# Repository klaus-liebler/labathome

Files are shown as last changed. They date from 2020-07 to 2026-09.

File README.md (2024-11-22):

# lab@home

<a target="_blank" href="https://icons8.com/icon/cUjTrEUoGJ2Z/xing">Xing</a> icon by <a target="_blank" href="https://icons8.com">Icons8</a>
<a target="_blank" href="https://icons8.com/icon/3tC9EQumUAuq/github">GitHub</a> icon by <a target="_blank" href="https://icons8.com">Icons8</a>
<a target="_blank" href="https://icons8.com/icon/IuI5Yd3J3qcC/linkedin">LinkedIn</a> icon by <a target="_blank" href="https://icons8.com">Icons8</a>

## Was steckt dahinter?
Das Projekt "lab@home" entstand zu Beginn der Corona-Pandemie. Als Lehrer in einer Hochschule der angewandten Wissenschaften war es dem Initiator ein Anliegen, seinen Studierenden auch 
während des Lockdowns Zugang zu Laborexperimenten in den Bereichen Steuerungstechnik, Regelungstechnik und Informationstechnik zu geben. Leider konnten die Studierenden nicht
mehr in die Hochschullabors, also musste das Labor zu den Studierenden. Nur leider wäre ein Container voll Material pro Student etwas zu aufwändig. Etwas kleineres und vor allem
kostengünstigeres musste her. Und damit waren die grundsätzlichen Anforderungen umrissen und der Initiator machte mich ans Design...

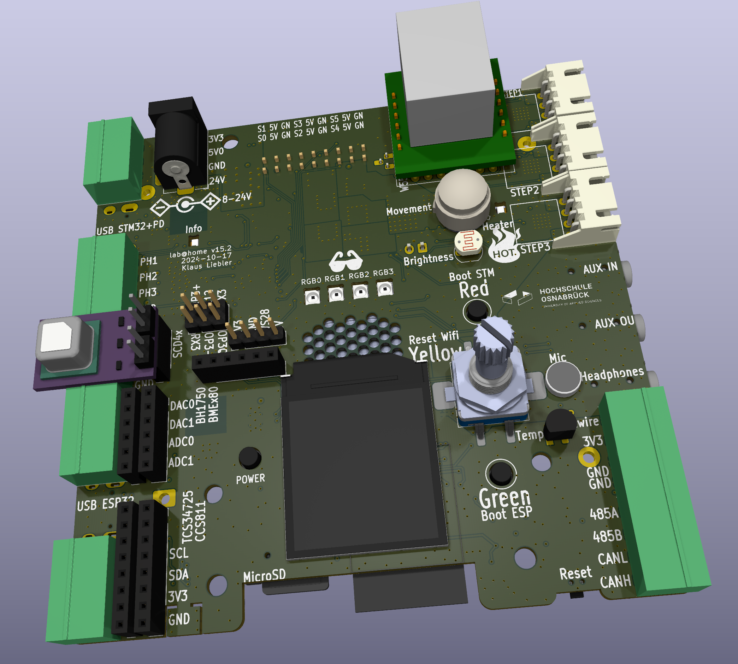
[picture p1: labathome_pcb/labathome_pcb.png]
Rendering


## Was gehört zu lab@home und was kann man damit machen?
Lab@home besteht aus
- einem Hardware-Design
- einer Softwarekomponente
- dieser Dokumentation
- der Beschreibung von Laborexperimenten (nicht veröffentlicht, auf Anfrage stelle ich das gerne zur Verfügung)

Der Entwickler bezeichne lab@home als eine Lehr- und Lernplattform für den Einsatz in Bildungseinrichtungen in den Disziplinen Steuerungstechnik, Regelungstechnik und Informationstechnik.
Ein besonderer Fokus liegt dabei auf der Gebäudeautomation

## Was sind die einzigartigen Merkmale von lab@home?
Lab@home
- ist quelloffen und soll unter der MIT-Lizenz jedem Nutzen stiften!
- kann komplett über den Browser bedient werden   
- ist preiswert und unproblematisch nachbaubar
- kann vielfältig eingesetzt werden

## Genug des Blabla - bitte technisch konkret!
Die Hardware von lab@home ist auf einer 10x10cm großen Platine aufgebaut und enthält die folgenden Komponenten:
- Dual-Prozessor-Konzept
    - Applikation: ESP32-S3 (8M Flash, 2,5MB RAM, Wifi, Bluetooth)
    - I/O & Realtime: STM32G431 (128k Flash, 32k RAM)
- Speichererweiteung über microSD-Slot
- Kommunikation
  - Interne Busse: I2c & 1Wire
  - Extern: Wifi, Bluetooth, RS485 (z.B. für Modbus), CAN (z.B. für CANopen oder OBD2)
  - Optional durch Steckmodule: Ethernet (W5500), GSM (SIM7080G), LoRaWan (RFM95), 2,4GHz (NRF24L01)
- Benutzerinteraktion
  - Taster, Inkrementalencoder
  - IPS-Display 240x240 Pixel, 1,3Zoll (ST7789)
  - Vier RGB-LED (WS2812)
  - Lautsprecher, Mikrofon, Klinkenbuchsen für Aux-In, Line-Out, Kopfhörer (NAU88C22)
- Sensorik
  - Lufttemperatur, Temperatur des Heizwiderstandes (2x DS18B20)
  - Luftfeuchtigkeit (SHT20)
  - Umgebungshelligkeit (LDR)
  - Ausrichtungs und Beschleunigungssensor (LSM6DS3)
  - PIR-Bewegungsmelder
  - Drei universelle ADC-Eingänge, davon einer mit Spannungsteiler
  - Spannungs- und Strommessung
  - Eingänge für Hall-Encoder
  - Optional durch Steckmodule: CO2, Luftqualität, Distanzsensor, Farbsensor
- Aktorik
  - Heizwiderstand, Lüfter, weiße Power-LEDs (alle PWM-Ansteuerung)
  - Zwei universelle DAC-Ausgänge, davon einer mit 0-10V
  - Dreiphasiger Motortreiber (Brushless) (DRV8313)
  - Drei Schrittmotor-Treiber (TMC2209)
  - Anschlüsse für vier (optional sechs) Servos
- Stromversorgung
  - USB
  - USB PD oder PPS (max 20V, 5A, umgesetzt über das UCPD-Peripherial im STM32G431)
  - Hohlstecker 5,5mm
  - MC-Klemmen
  - 18650-Akku
  - Involviert in die Stromversorgung sind 
    - IP5306: Akkuladung, Boot-Converter auf 5V
    - TPS54202: Synchroner Abwärtswandler 8...24V -> 5V
    - TPS2116: Umschaltung zwischen Spannungsquellen
    - AMS1117: LDO 5V->3,3V

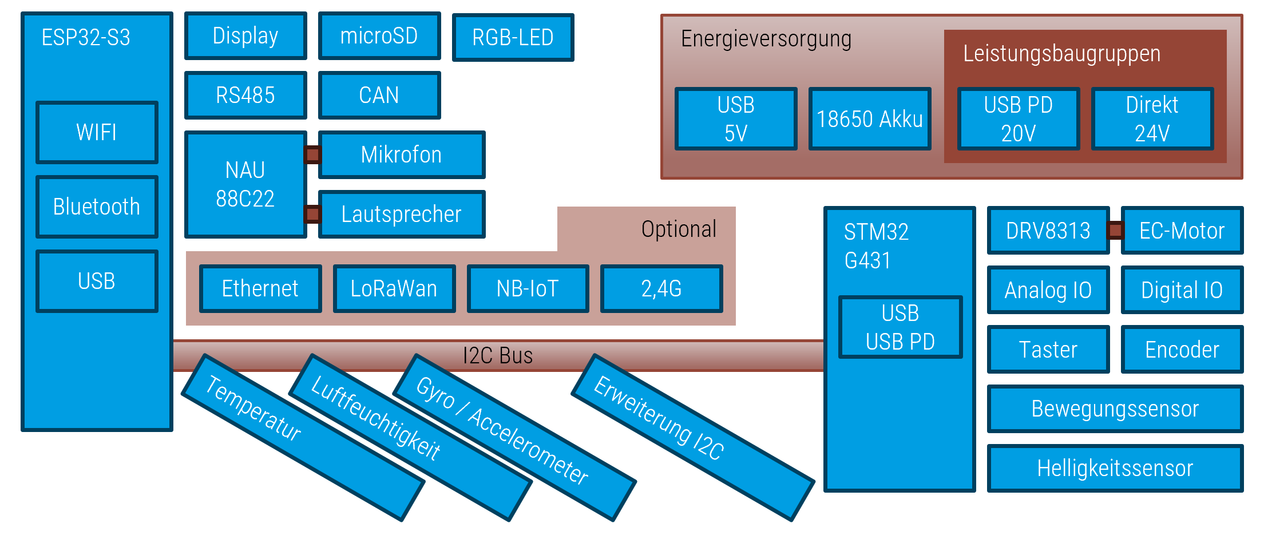
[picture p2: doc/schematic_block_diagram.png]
Blockdiagramm


Die Software von lab@home besteht aus der eigentlichen Firmware und einer Webapplikation. Viele Experimente können über die Webapplikation gesteuert werden.
Nach dem ersten Start öffnet lab@home einen WIFI-Accesspoint, über den die Webapplikation erreichbar ist und labathome auch in ein bestehendes WIFI-Netzwerk eingebunden werden kann. Dank der Webapplikation benötigt der Anwender keine lokale Software und die Nutzung ist unabhängig vom Betriebssystem möglich (viele meiner Studierenden verwenden Apple-Rechner oder haben nur Chromebooks oder Android-Tablets). Die Webapplikation hat diese Features:
- Programmierung von lab@home mit Funktionsblöcken in Anlehnung an IEC61131 und VDI3814
  - darauf ist der Entwickler besonders stolz!!
  - Speichern und Laden von Programmen möglich
  - Es ist möglich, eine Startapplikation festzulegen, die lab@home automatisch beim Einschalten lädt und ausführt
  - Integrierter Debugger
  - Integrierter Simulator
  - Technisches Detail: Das Funktionsblock-Diagramm wird von einem Java-Script-Compiler im Browser zu einem Binärcode compiliert und "online" zum Mikrocontroller gesendet. Dieser bringt dann das Programm unmittelbar zur Ausführung
- Oberfläche für das Experiment "Identikation einer Regelstrecke mit dem Sprungantwort-Versuch"
- Oberfläche für das Experiment "Parametriertung eines PID-Reglers mit der Einstellregeln nach Chien, Hrones und Reswick"
- Konfigurationsoberfläche für Wifi
- Konfigurationsoberfläche für diverse Systemeinstellungen (in Arbeit)
- Online-Aktualisierung der kompletten Systemsoftware (in Arbeit)

# Getting Started - Hardware
Die aktuellen Schaltpläne und Layouts im KiCad-Format befinden sich im Verzeichnis labathome_pcb

# Getting Started - Software

Die Software muss individuell für jedes Board compiliert werden, weil während des von Gulp gesteuerten Gesamt-Build-Prozesses diverse individuelle Dateien erzeugt und eincompiliert werden. Dazu gehören:
- LabAtHome meKicldet sich per Sprachausgabe betriebsbereit. Die Ausgabe enthält auch den Hostnamen der Platine, der sich wiederum aus der MAC-Adresse ableitet. Alle Sprachausgaben werden zum Build-Zeitpunkt über Google TTS erzeugt und in Form von MP3-Dateien im Flash abgelegt. Ach ja, LabAtHome kann natürlich MP3 wiedergeben!
- LabAtHome kommuniziert natürlich verschlüsselt! Dazu wird ein privater Schlüssel und ein Zertifikat für eben den Hostnamen erzeugt

Selbst kompilieren? Geht!
- Installiere das ESP-IDF!
- Installiere Node.js
- Ich gehe davon aus, dass alle Checkouts in c:/repos erfolgen. Viele Pfade sind in den Konfigurationsdateien absolut und auf diesen Pfad angepasst
- Checke dieses Repo https://github.com/klaus-liebler/labathome aus
- Checke das repo https://github.com/klaus-liebler/espidf-components aus
- Rufe "npm update" in C:\repos\labathome\espidf-component-labathome\web auf
- Rufe "npm update" in "C:\repos\labathome\espidf-component-labathome\builder" auf
- Rume "npm run gulp" in "C:\repos\labathome\espidf-component-labathome\builder" auf. Dieses erstellt individuelle Board-Files und die gesamte Web-Anwendung
- TBC

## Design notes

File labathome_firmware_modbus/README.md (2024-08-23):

# Lab@Home Modbus

This is the implementation of a Modbus RTU Slave running on Lab@Home Hardware. (Almost) all sensors and actors are accessible via modbus protocol

This is an expert tool:

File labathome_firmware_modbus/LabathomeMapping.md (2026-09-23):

# General Modbus Information

## Register

| REGISTER NUMBER | REGISTER ADDRESS HEX | TYPE | NAME | TYPE |
|:---:|:---:|:---:|:---:|:---:|
| 1-9999 | 0000 to 270E | Read / Write | Discrete Output Coils | DO |
| 10001-19999 | 0000 to 270E | Read | Discrete Input Contacts | DI |
| 30001-39999 | 0000 to 270E | Read | Analog Input Registers | AI |
| 40001-49999 | 0000 to 270E | Read / Write | Analog Output / Holding Registers | AO |

## Function Codes

| FUNCTION CODES | FUNCTION | TYPE | ACCESS TYPE |
|:---:|:---:|:---:|:---:|
| 01 (0x01) | Read DO, Read Discrete Output Coil | Bool | Read |
| 02 (0x02) | Read DI, Read Discrete Input Contact | Bool | Read |
| 03 (0x03) | Read AO, Read Analog Output Holding Register | 16 Bit | Read |
| 04 (0x04) | Read AI, Read Analog Input Register | 16 Bit | Read |
| 05 (0x05) | Write Discrete Output Coil | Bool | Write |
| 06 (0x06) | Write Single Analog Output / Holding Registers | 16 Bit | Write |
| 15 (0x0F) | Write Multiple Discrete Output Coils | Bool | Write Multiple |
| 16 (0x10) | Write Multiple Analog Outputs / Holding Registers | 16 Bit | Write Multiple |

## Modbus Mapping

These are the addresses and the formats at Lab@Home by Klaus Liebler.  
Addresses are **0-Based**.

### Discrete Output Coils (FC5 / FC15)

| Register (0-Based) [Offset]| Function|
|:---:|:---:|
| 0 | Relay K3 |

### Discrete Input Contacts (FC2)

| Register (0-Based) [Offset]| Function|
|:---:|:---:|
| 0 | Green Button |
| 1 | Red Button |
| 2 | Yellow / Encoder Button |
| 3 | Movement Sensor |

### Holding Registers (FC3 / FC6)

| Register (0-Based) [Offset] | Function |

|:---:|:---:|
| 0 | Not connected |
| 1 | Servo 0, Position in Degrees 0...180 |
| 2 | Servo 1, Position in Degrees 0...180 |
| 3 | Servo 2, Position in Degrees 0...180 |
| 4 | Servo 3, Position in Degrees 0...180 |
| 5 | Fan 0, Power in Percent 0...100 |
| 6 | Fan 1, Power in Percent 0...100 |
| 7 | Heater, Power in Percent 0...100 |
| 8 | White Power LED, Power in Percent 0...100 |
| 9 | RGB LED 0, Color in RGB565 |
| 10 | LED 1 |
| 11 | LED 2 |
| 12 | LED 3 |
| 13 | Relay State (Alternative to Coil 0), 0 means off, all other values on |
| 14 | Play Sound, 0 means silence; try other values up to 9 |

### Input Registers (FC4)

| Register (0-Based) [Offset] | Function |
|:---:|:---:|
| 0 | CO2 [PPM] |
| 1 | Air Pressure [hPa] |
| 2 | Ambient Brightness [?] |
| 3 | Analog Input [mV] (Channel Analog Input or Rotary Encoder I34) |
| 4 | Button Green [0 or 1] |
| 5 | Button Red [0 or 1] |
| 6 | Button Yellow/Encoder [0 or 1] |
| 7 | Fan 1 RPM |
| 8 | Heater Temperature [°C * 100] (Temperature of the "Tripod") |
| 9 | Encoder Detents |
| 10 | Movement Sensor [0 or 1] |
| 11 | Distance Sensor [millimeters] |
| 12 | Analog Voltage on Pin 35 (Channel Movement or Fan 1 Sense I35) |
| 13 | Placeholder |
| 14 | Placeholder |
| 15 | Relative Humidity AHT21 [%] |
| 16 | Temperature AHT21 [°C * 100] |
| 17 | Relative Humidity BME280 [%] |
| 18 | Temperature BME280 [°C * 100] |
| 100 | Firmware Version |

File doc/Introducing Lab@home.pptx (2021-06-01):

## Praktikum mit Lab@Home Steuerungs- und Regelungstechnik überall einfach – und einfach probieren!

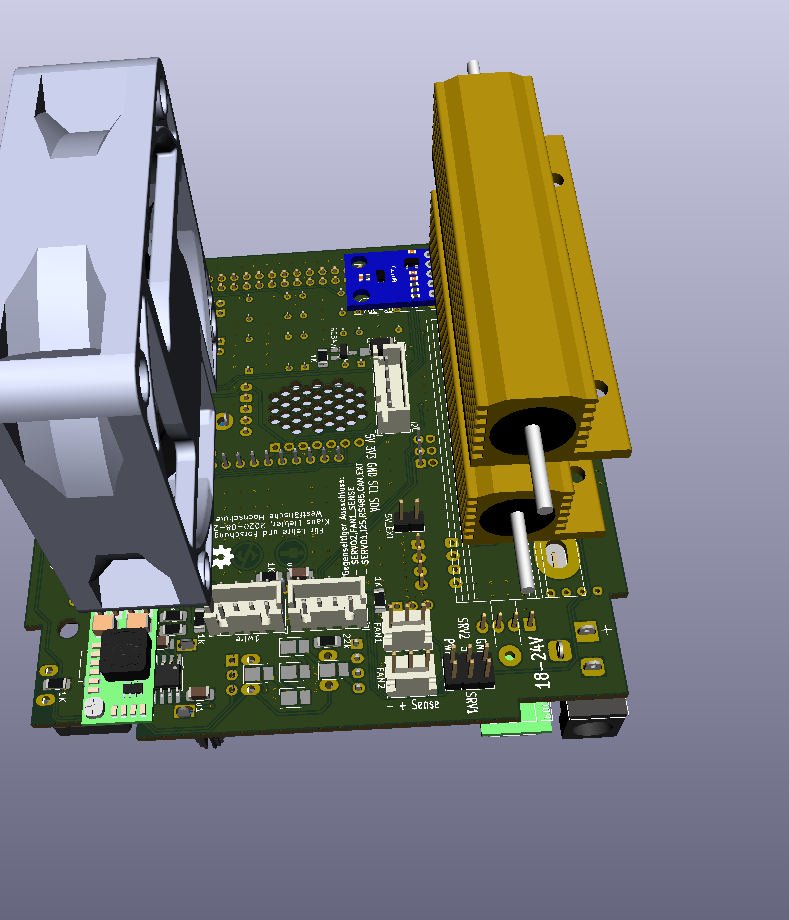
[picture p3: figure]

RT&ST kompakt - Prof. Dr. Klaus M. Liebler

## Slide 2

## Praktikum Steuerungstechnik Was ist Lab@Home?

- Eine Experimentier- und Lehrplattform für die Steuerungs- und Regelungstechnik mit Fokus auf die Gebäudeautomation
- Universell: Regelungstechnik, Steuerungstechnik, Informationstechnik
- Kabelarm: USB-C anstecken und los geht es
- Leistungsfähig: 32bit Dual Core 240MHz Microcontroller
- Webbasiert: Ein Laptop / Tablet /Handy mit einem Webbrowser genügt!
- Frei: Hard- und Software stehen unter einer freien Lizenz auf Github zur Verfügung
- Programmierbar: Sie können das Verhalten im Browser mit „Funktion Block“ Programmierung festlegen oder nativ in C++ programmieren
- Günstig: Bauteilekosten je nach Ausbaustufe 15€….35€, DIY
- Romantisch: Bei Bedarf kann er auch Webradio und (visuelle) Kaminfeuersimulation…

## Praktikum Steuerungstechnik Lab@Home hat…

- Microcontroller mit integriertem Wifi
- 2 Taster, einen Drehencoder
- IPS Farbdisplay, 240x240 Pixel, 1W-Lautsprecher
- 8 einzeln steuerbare RGB-Led, Eine weiße Hochleistungs-LED, Relaisausgang
- Mikrofon, Temperatursensor für Heizwiderstände und Raum, Luftdrucksensor, Luftfeuchtesensor, Helligkeitssensor, Bewegungsmelder
- 2 Servo-Anschlüsse, 2 Lüfter-Anschlüsse (einer mit Tacho-Signal), 2 Heizwiderstände
- Stromversorgung aus 24V oder USB-C-Netzteil
- Kommunikation drahtgebunden: RS485 (Modbus, BacNET, opt.), CAN-Bus (opt.)
- Kommunikation drahtlos: Wifi, Bluetooth, Lorawan (opt.), GSM (opt.)
- Für „Steuerungstechnik mit Verdrahtung“: Ein Zeitrelais 2xUM, zwei Relais 2xUM, zwei Taster, zwei LEDs

## Praktikum Steuerungstechnik Lab@Home unterstützt die Experimente:

- Verbindungsprogrammierte Logik (UND/ODER/Selbsthaltung/Zeitverzögerung etc. mit Tastern, Relais, LED)
- Funktionsblock-orientierte Simulation
- Funktionsblock-orientierte Programmierung
- Identifikation/Auslegung/Regelung/Störgröße für eine Heizregelstrecke (PTN mit PID)
- Identifikation/Auslegung/Regelung einer Lichtregelstrecke (P mit P)
- (Aktuell in Umsetzung) Identifikation/Regelung einer Füllstandsregelstecke (I mit 2Punkt)
- Drehzahlregelung eines Ventilators
- Volumenstromregelung eines Ventilators
- SMOPLA::PTN: Elektronisches PT1x3-Glied
- IoT: Umgebung sensorisch erfassen und via Wifi/LoRaWan/GSM „in die Cloud“ bringen. Aktorbefehle empfangen und umsetzen
  - Projektbeispiel: Erfassung der Umdrehungen eines Gaszählers mit Hall-Sensor; Übermittlung / Verarbeitung / grafische Auswertung in mehreren „hintereinandergeschalteten“ Cloud-Services
- Kommunikation: Agiere als BACnet- oder als Modbus-Gerät (Master/Slave, RS485/IP)

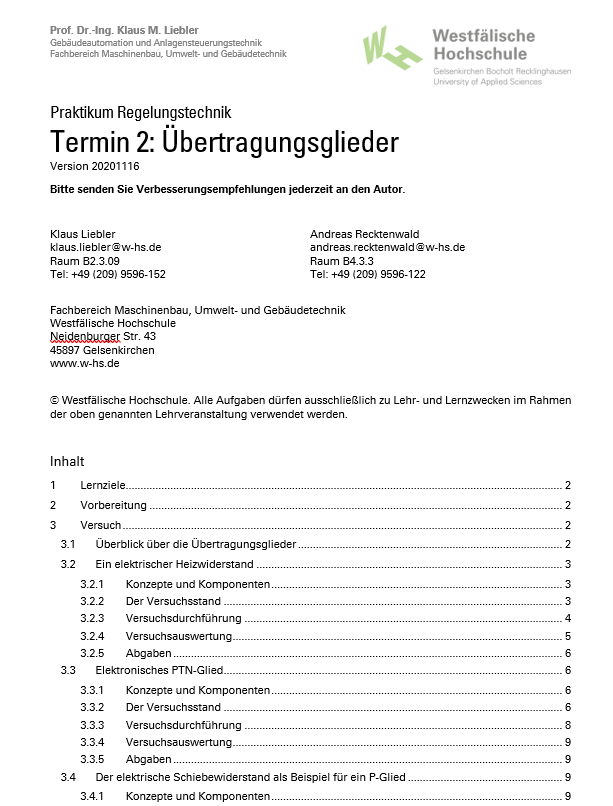
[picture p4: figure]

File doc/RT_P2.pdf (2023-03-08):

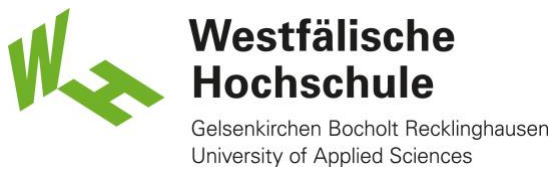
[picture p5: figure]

Prof. Dr.-Ing. Klaus M. Liebler
Gebäudeautomation und Anlagensteuerungstechnik Fachbereich Maschinenbau, Umwelt- und Gebäudetechnik

## Praktikum Regelungstechnik

# Termin 2: Übertragungsglieder

Version 2022-05-04

Bitte senden Sie Verbesserungsempfehlungen jederzeit an den Autor.

Klaus Liebler
klaus.liebler@w-hs.de
Raum B2.3.09
Tel: +49 (209) 9596-152

Andreas Recktenwald
andreas.recktenwald@w-hs.de Raum B4.3.3
Tel: +49 (209) 9596-122

Fachbereich Maschinenbau, Umwelt- und Gebäudetechnik Westfälische Hochschule
Neidenburger Str. 43
45897 Gelsenkirchen
www.w-hs.de

© Westfälische Hochschule. Alle Aufgaben dürfen ausschließlich zu Lehr- und Lernzwecken im Rahmen der oben genannten Lehrveranstaltung verwendet werden.

Inhalt

Prof. Dr.-Ing Klaus M. Liebler

## 1 Lernziele

- Die Studierenden können statisches und dynamisches Übertragungsverhalten voneinander unterscheiden und können entscheiden, ob bei einem Übertragungsglied in einem bestimmten Anwendungskontext eine statische Betrachtung genügt oder ob dynamisches Verhalten ermittelt werden muss
- Die Studierenden können statische Kennlinien und dynamische Sprungantworten messtechnisch ermitteln, einem Standardübertragungsverhalten zuordnen und Kennwerte ermitteln.

## 2 Vorbereitung

- Lesen Sie sich diese Versuchsbeschreibung gründlich durch
- Wiederholen Sie die relevanten Inhalte der Vorlesung.
- Bereiten Sie die Auswertungstabellen und die Diagramme für die Versuchsauswertungen wie im Text angegeben vor. Stellen Sie sicher, dass Sie bei digitalen Vorlagen bei der Versuchsdurchführung Zugriff auf diese Vorlage haben (USB-Stick, Online-Speicher, sich selbst per Mail senden…)

Stichwörter:

Statisches und dynamisches Verhalten eines Übertragungsgliedes, Sprungantwort

## 3 Versuch

Im Rahmen dieses Versuchs stellen wir Ihnen verschiedene Ausführungen technischer Übertragungsglieder zur Verfügung. Wir erklären Ihnen außerdem, wo dieses Übertragungsglied (ggf. in anderer Bauform und Dimensionierung) in der Praxis zum Einsatz kommt. Die Aufgabenstellung für jedes Übertragungsglied ist dann grundsätzlich immer sehr ähnlich:

- Überlegen Sie, ob Sie statisches oder dynamisches Verhalten untersuchen möchten.
- Überlegen Sie, welche Testsignale (physikalische Einheit und Wertebereich) Sie verwenden möchten.
- Überlegen Sie basierend auf Ihrem Erfahrungswissen als Fast-schon-fertig-Ingenieur, welchen Verlauf Sie erwarten.
- Führen die den Versuch durch. Prüfen Sie dabei ständig, ob Ihre Erwartung zumindest näherungsweise eingehalten wird und ob ein gefährlicher Zustand des Testobjektes erreicht wurde.

Gegenbeispiel: Ich hatte vor einiger Zeit eine Studentengruppe damit beauftragt, erste Testmessungen mit einem Experimentieraufbau „lab@home“ (lernen Sie auch noch kennen) durchzuführen. Eine Spannung sollte an einen Heizwiderstand angelegt werden, der einen kleinen Messraum aufheizen sollte. Fraglich war, wie lange das Aufheizen des Raumes bei einer bestimmten Betriebsspannung ungefähr dauert. Die Studierenden legten diese Spannung an, der Widerstand wurde heiß und heißer. Schließlich begann es zu rauchen und zu kokeln. Doch die Studierenden heizten weiter, ohne über die Sinnhaftigkeit nachzudenken. Unglücklicherweise hatte ich die Belastungsfähigkeit „mit Kühlung“ und „ohne Kühlung“ vertauscht…

### 3.1 Überblick über die Übertragungsglieder

Bezeichnung | Eingangsgröße | Ausgangsgröße | Einsatz
Heizwiderstand | Steuerspannung [V] | Temperatur der Spei- chermasse [°C] | Nachtspeicherheizung

RC-Glied | Spannung [V] | Spannung [V] | Filterstufen im Audio-
| | | Bereich
Schiebewiderstand | Position des Schiebers
| [mm] | Elektrischer Wider-
| | stand [Ohm] | Audio-Mischpult -
| | | Lautstärke

### 3.2 Ein elektrischer Heizwiderstand (PTN-Verhalten)

3.2.1 Konzepte und Komponenten
In der regelungstechnischen Praxis hat man es häufig mit Regelstrecken zu tun, die näherungsweise PT1 oder PTn-Verhalten aufweisen. Aus dem Skript kennen Sie bereits einige Beispiel. Ein gutes und in der Umwelt- und Gebäudetechnik sehr praxisrelevantes Beispiel sind Temperaturstrecken. Aus der Thermodynamik kennen Sie die Differenzialgleichungen, mit denen sich ein Wärmeübergang von einem Körper zum anderen (z.B. vom Wasservorlauf auf den Heizkörper oder vom Heizkörper zur Raumluft) modellieren lässt. Ohne zu weit in die Details abzugleiten: Jeder Wärmeübergang verhält sich letztlich wie ein PT1-Glied. Die Temperatur des Zielkörpers steigt dabei zunächst schnell an und nähert sich dann asymptotisch der Temperatur des Quellkörpers, der bei Temperaturstecken dann auch den sog. Beharrungsendwert markiert.

Als vereinfachtes Modell einer Heizung (zur Erwärmung eines Raumes, zur Erwärmung von Flüssigkeiten in chemischen Reaktoren) verwenden wir einen elektrischen Hochlastwiderstand. Wenn dieser von Strom durchflossen wird, entsteht ein Spannungsabfall. Die dabei freiwerdende Energie wird in Wärme umgesetzt. Abbildung 1 zeigt den im Versuch eingesetzten Hochlastwiderstand. Sichtbar ist das Aluminiumgehäuse. Der eigentliche Widerstand – ein Drahtwiderstand befindet sich vergossen und isoliert im Inneren. Innerhalb des Widerstandes finden bereits zwei relevante Wärmeübergange statt: Von der Drahtwicklung zur Vergussmasse und von der Vergussmasse zum metallischen Kühlkörper.

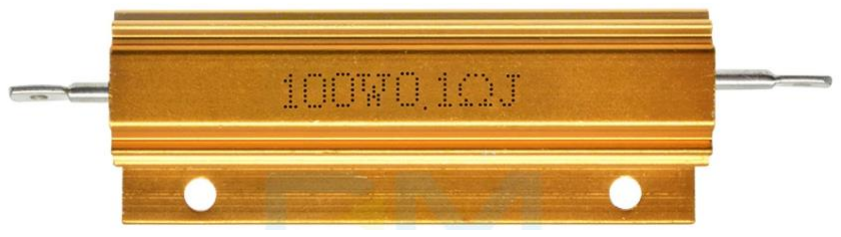
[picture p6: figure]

Abbildung 1: Hochlastwiderstand im Metallgehäuse

Der Widerstand ist Teil des Experimentiersystems lab@home. Ihr Dozent hat dieses System mit dem Ziel entwickelt, jedem Studierenden den selbständigen und preiswerten Aufbau eines kompletten regelungstechnischen Labors zu ermöglichen, was dann auch zu Hause für Experimente genutzt werden kann. Heute soll die Anwendung „Experimentelle Bestimmung von Streckenparametern“ im Vordergrund stehen.

Verbrennungsgefahr! – Der Heizwiderstand wird bis zu 100°C heiß!

3.2.2 Der Versuchsstand
Die zentrale Komponente des Versuchsstandes zeigt Abbildung 2

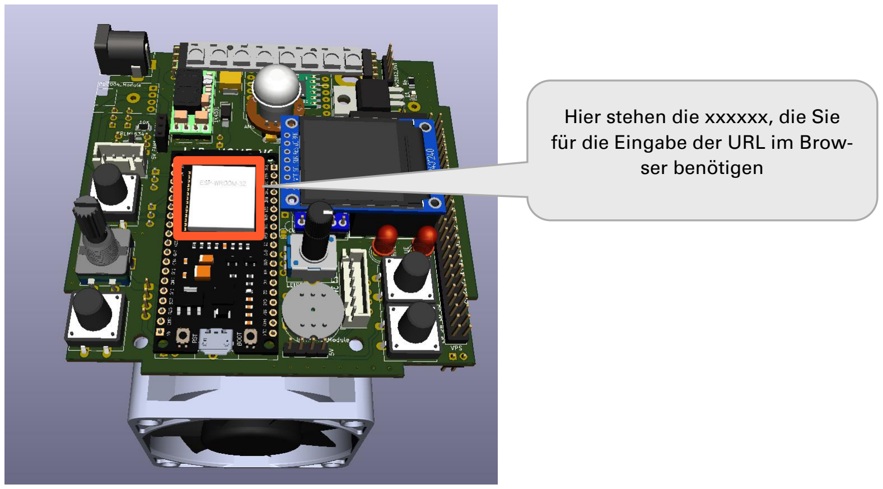
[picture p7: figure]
Hier stehen die xxxxxx, die Sie für die Eingabe der URL im Brow- ser benötigen

Abbildung 2: Lab@Home als 3D-Rendering

Achten Sie auf die Beschriftung auf der silbernen Abdeckung des zentralen Microcontrollers.

3.2.3 Versuchsdurchführung
Wie bereits weiter oben dargestellt, handelt es sich bei Temperaturstecken um Regelstrecken MIT Verzögerungen. Eine rein statische Betrachtung genügt da nicht. Wir müssen also eine dynamische Betrachtung per Sprungantwort durchführen. Sie können das aus der Praxis bestätigen: Wenn Sie eine neue Heizung bekommen, dann interessiert Sie nicht nur, wie warm es wird, sondern auch, wie schnell diese Temperatur erreicht wird. Lab@home bietet eine webbasierte Oberfläche, die Sie bei der Versuchsdurchführung unterstützt. Gehen Sie wie folgt vor:
- Schließen Sie lab@home an die Spannungsversorgung (24V DC) an. Warten Sie etwa 10 Sekunden
- Öffnen Sie auf dem PC den Internet-Browser und geben Sie ein http://labathome-xxxxxx.lan. Ersetzen Sie xxxxx durch die Ziffern und Zahlen, die auf der Abschirmung des zentrales Microcontrollers notiert sind (siehe Abbildung 2)
- Es erscheint die Web-Oberfläche von labathome (siehe Abbildung 3). Klicken Sie links auf „Heater Experiment“ (1). Klicken Sie dann oben auf „Open Loop“ (2).

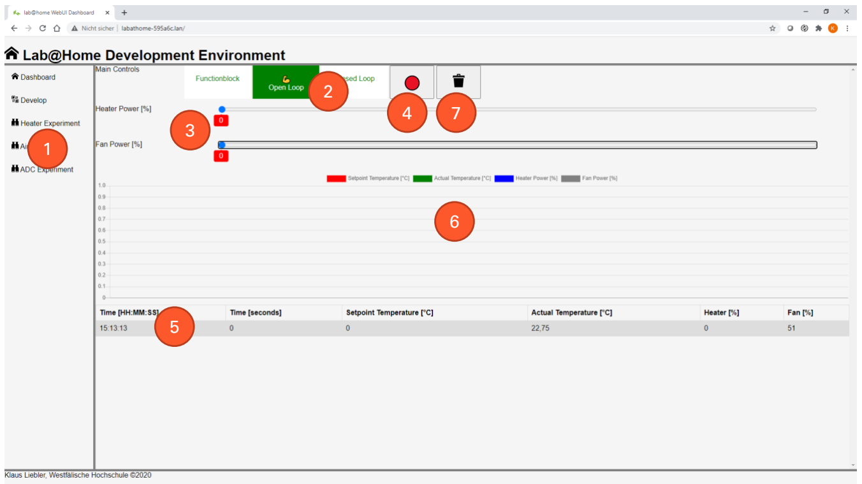
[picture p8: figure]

Abbildung 3: Bedienoberfläche von Lab@Home

- Sie können mit den Schiebreglern (3) die Leistung des Heizwiderstandes und des Lüfters einstellen. Probieren Sie das mit dem Lüfter einfach mal aus. Vom Heizwiderstand selbst lassen Sie bitte die Finger!
- Die aktuellen Messwerte und Vorgabewerte werden im unteren Bereich (4) tabellarisch angezeigt.
- Mit dem Button (4) aktivieren Sie die Aufnahme. Dann wird sekündlich der aktuelle Messwert in die Tabelle (5) geschrieben und alle 5 Sekunden im Diagrammbereich (6) ein neues Werte-Tupel geschrieben. Ein nochmaliger Mausklick auf den Button (4) beendet die Aufnahme. Mit dem Papierkorb-Button (7) löscht man alle Einträge aus der Tabelle und dem Diagramm.

Jetzt geht es richtig los:

- Falls Sie gerade noch am Spielen sind: Stoppen Sie die Aufnahme und löschen Sie alle Einträge. Schalten Sie auch den Lüfter aus.
- Starten Sie die Aufnahme
- | Stellen Sie den „Heater Power“-Schieberegler sprunghaft ( | , also „schnell“) von 0 auf 20% Leis-
| tung ein.
- Beobachten Sie den Temperaturverlauf und entscheiden Sie, wann der Beharrungsendwert erreicht
| ist. Beenden Sie dann die Aufnahme.
3.2.4 | Versuchsauswertung
Kopieren Sie den Inhalt der Tabelle (einschließlich Überschriften) in ein neues Excel-Dokument und erzeugen Sie ein „x-y-Liniendiagramm“ mit den „Sekunden auf der Abszisse und der „Actual Temperature“ auf der Ordinate. Falls wir in der Vorlesung bereits so weit gekommen sind: Skalieren Sie das Diagramm so, dass Sie im Ausdruck gemäß „Wendetangentenmethode“ die relevanten Parameter des Heizwiderstandes bestimmen können. Achten Sie bei der Berechnung des Verstärkungsfaktors darauf, dass Sie nicht mit 100% geheizt haben.
Parameter | Wert
Verzugszeit TE

Ausgleichszeit TB

Proportionalbeiwert KP

3.2.5 Abgaben
- Excel-Datei mit Sprungantwort als Wertetabelle und Diagramm

### 3.3 Drei gekoppelte RC-Glieder (jeweils PT1-Verhalten)

In diesem Versuch werden wir die Sprungantwort von einstellbaren PT1-, PT2- und PT3-Gliedern untersuchen.

3.3.1 Konzepte und Komponenten
Bei einem PT1-Glied handelt es sich um ein lineares Übertragungsglied, dass in der Regel aus einem Speicherelement und einem den Fluss hemmenden Element besteht. Je nach Technologie kann es dafür unterschiedliche Realisierungen geben.
Technologie | Speicher | Flusshemmendes Element
Elektrisch | Kondensator | Widerstand
Thermisch | Masse | Wärmeübergang
Pneumatisch | Druckbehälter | Drossel

Im vorliegenden Fall schauen wir uns die elektrische Implementierung von drei hintereinander geschalteten PT1- Gliedern an, die insgesamt dann ein PT3-Glied ergeben.

3.3.2 Der Versuchsstand
Der Versuchstand „smopla::PTN“ besteht aus einer Platine mit einer elektronischen Schaltung. Auf der Vorderseite sind Bedienelemente zur Erzeugung eines Sprungs und zur Feineinstellung der einzelnen PT-Glieder angebracht.
BEZEICHNUNG | FUNKTION
LOAD | Taster zur Aktivierung des Sprunges. Solange der Taster gedrückt
wird, wird das erste PT1-Glied mit einer Spannung von 3,3V geladen. Wird er losgelassen, wird mit 0V wieder entladen.
ADJUST PT1 / PT2 /PT3 | Potentiometer zur Einstellung der Verzögerungszeit des ersten / zwei-
ten / dritten PT1-Gliedes
PT1 / PT2 / PT3 | Laborbuchsen zum Abgriff der Spannungen nach dem ersten / zweiten
/ dritten PT1-Glied
GND | Laborbuchse mit Massepotential

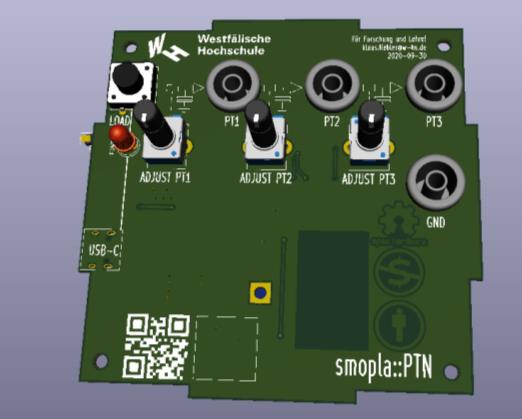
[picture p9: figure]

Abbildung 4:smopla:PTN (Vorderseite)

Die Vorderseite ist zudem bedruckt mit dem vereinfachten Schaltplan von smopla::PTN. Zwischen Taster und Laborbuchsen finden Sie die wesentlichen Elemente des „entkoppelten elektrischen PT1-Gliedes“, also einen (einstellbaren) Widerstand, einen Kondensator und einen Impedanzwandler.

GRÖßE | WERT
WIDERSTAND | Einstellbar zwischen 10kOhm und 20kOhm
KONDENSATOR | 470uF
IMPEDANZWANDLER | Verstärkungsfaktor 1

Wenn Sie smopla::PTN umdrehen, sehen Sie diese Komponenten direkt vor sich. Für Kenner der Materie zeige ich den relevanten Ausschnitt des Schaltplans (siehe Abbildung 5). Der Taster gibt ein 3.3V-Signal an „RELAY_ON“ und schaltet über den Transistor das Relais an.

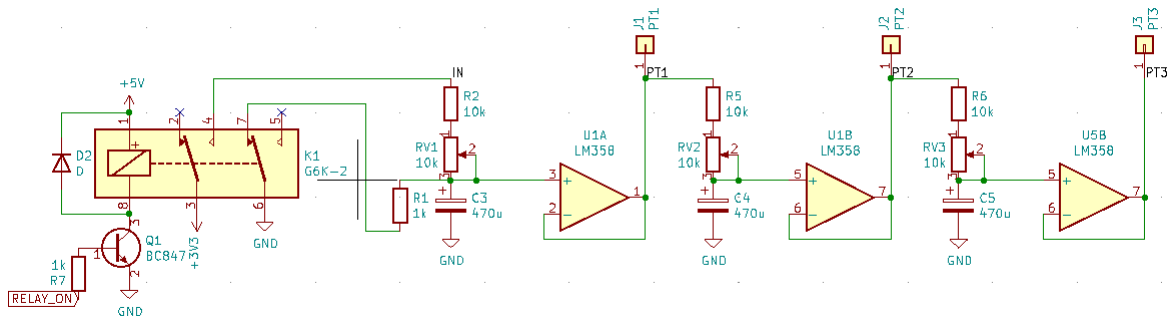
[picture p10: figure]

Abbildung 5: Schaltplan der RC-Glieder und Impedanzwandler

Neben dem im Schaltplan dargestellten Komponenten befindet sich eine USB-basierte Stromversorgung, ein hochgenauer Analog-Digital-Wandler und ein WIFI-Mikrocontroller auf der Platine.

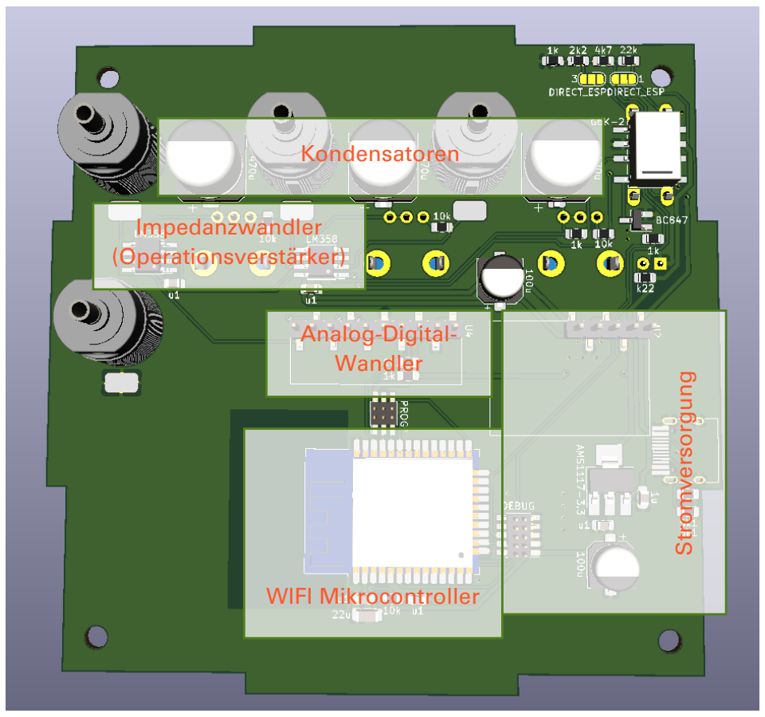
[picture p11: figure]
WIFI Mikrocontroller; Stromversorgung; Impedanzwandler (Operationsverstärker); Kondensatoren; Analog-Digital- Wandler

Abbildung 6: smopla::PTN (Rückseite)

3.3.3 Versuchsdurchführung
smopla::PTN bietet eine webbasierte Oberfläche, die Sie bei der Versuchsdurchführung unterstützt. Gehen Sie wie folgt vor:
- Schließen Sie smopla::PTN an ein USB-C-Netzteil (Handy-Ladegerät, Notebook-Netzteil) an und warten Sie einige Sekunden. smopla::PTN startet und bucht sich selbständig ins WIFI-Netz des Labors ein.
- Drehen Sie alle Einstellknöpfe ganz nach rechts.
- Öffnen Sie auf dem PC den Internet-Browser und geben Sie ein http://labathome-xxxxxx.lan. Ersetzen Sie xxxxx durch die Ziffern und Zahlen, die auf der Abschirmung des zentrales Microcontrollers notiert sind.
- Es erscheint die Web-Oberfläche von smopla::PTN. Klicken Sie links auf „ADC Experiment“. Es gilt die folgende Zuordnung:
GRÖßE | WERT
AIN0 | Eingangsspannung am ersten PT1-Glied
AIN1 | Ausgangsspannung des ersten PT1-Gliedes
AIN2 | Ausgangsspannung des zweiten PT1-Gliedes
AIN3 | Ausgangsspannung des dritten PT1-Gliedes
- Starten Sie den Aufzeichnungsmodus durch Klick auf das „Record“-Symbol.
- Drücken Sie jetzt den Load-Taster und halten Ihn gedrückt, bis alle Kurven – also insbesondere AIN3 – den Beharrungsendwert erreicht haben (dauert einige Zeit…)

- Stoppen Sie die Aufzeichnung durch Klick auf das „Stop“-Symbol und lassen Sie den Load-Taster los.

3.3.4 Versuchsauswertung
Kopieren Sie die Wertetabelle unter dem Diagramm zur detaillierten Auswertung in Excel (Sie müssen diese Tabelle nicht vorbereiten – das funktioniert einfach mit „Copy&Paste“).

Visualisieren Sie die Wertetabelle in Excel mit einem X-Y-Diagramm. Machen Sie sich dort nochmal klar, dass die Spannung nach dem ersten PT1-Glied unmittelbar steil ansteigt. Nach dem zweiten und insbesondere nach dem dritten Übertragungsglied ist zunächst ein flacher, dann ein steiler und dann wieder ein wieder flacher werdender Anstieg erkennbar – dort gibt es also einen Wendepunkt.

3.3.5 Abgaben
- Excel-Datei mit Sprungantwort als Wertetabelle und Diagramm
- | Falls wir in der Vorlesung bereits so weit gekommen sind: | Berechnen Sie die Zeitkonstante des
ersten PT1-Gliedes und beschreiben Sie, wie Sie diese Zeitkonstante im Diagramm finden.
- Beantworten Sie: Wie lange dauert es in etwa, bis das PT3-Übertragungsglied (also das Gesamt-
| Übertragungsglied) den Beharrungsendwert erreicht hat?

### 3.4 Ein elektrischer Schiebewiderstand (P-Verhalten)

3.4.1 Konzepte und Komponenten
Ein elektrischer Schiebewiderstand (siehe Abbildung 8) wandelt eine Schieberstellung x [cm] ohne Zeitverzögerung in einen Widerstandswert R [Ohm] um. Dazu greift ein beweglicher Schleifer auf einer Widerstandbahn oder einer Drahtwicklung an der eingestellten Position einen Teil des Gesamtwiderstandes ab. In der Praxis verwendet man Schiebewiderstände beispielsweise in Audio-Mischpulten (siehe Abbildung 9). Das Verhältnis zwischen x und R muss dabei nicht zwingend proportional sein, sondern kann beispielsweise auch einen logarithmischen Verlauf aufweisen (siehe Abbildung 10).

Ein Schiebewiderstand kann als ein Übertragungsglied mit x [cm] als Eingangsgröße und R [Ohm] als Ausgangsgröße modelliert werden (siehe Abbildung 7)

Abbildung 7: Schiebewiderstand als Übertragungsglied

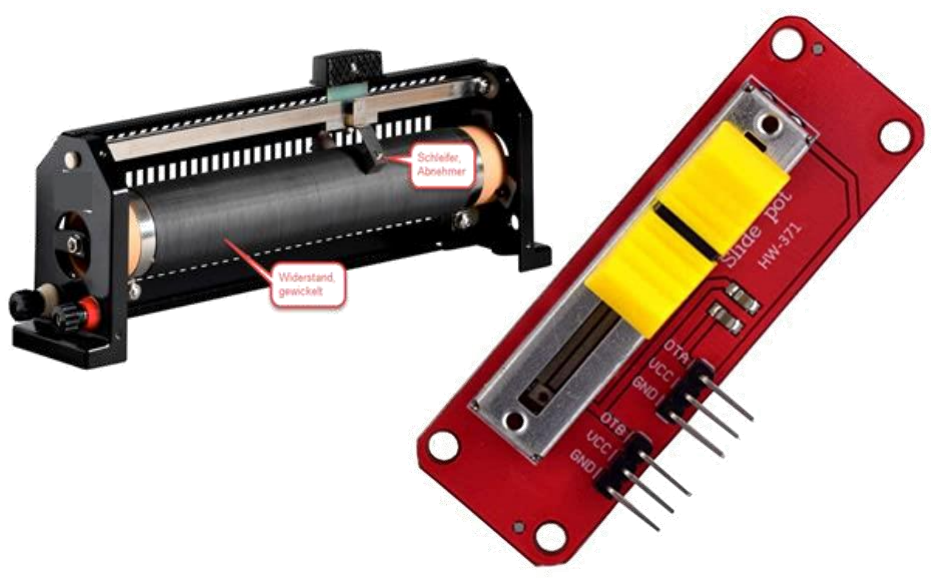
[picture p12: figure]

Abbildung 8: Schiebewiderstände

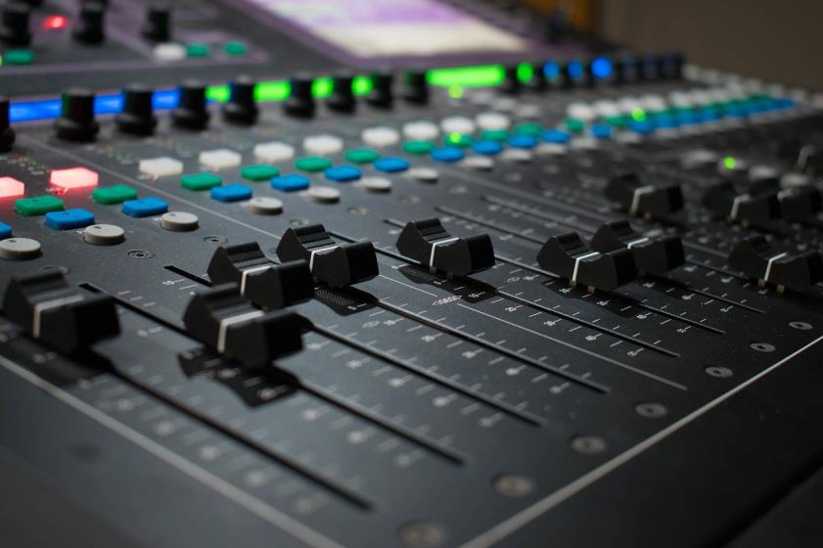
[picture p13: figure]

Abbildung 9: Schiebewiderstände in einem Mischpult (Quelle: Pixabay)

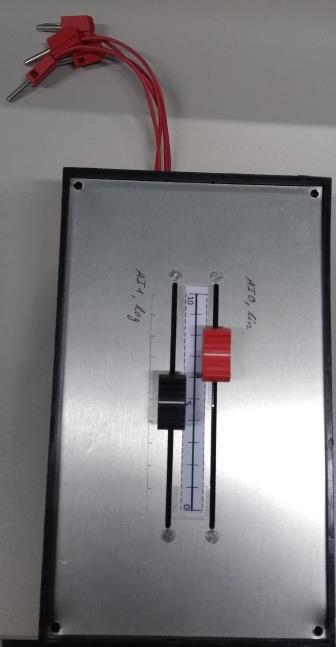
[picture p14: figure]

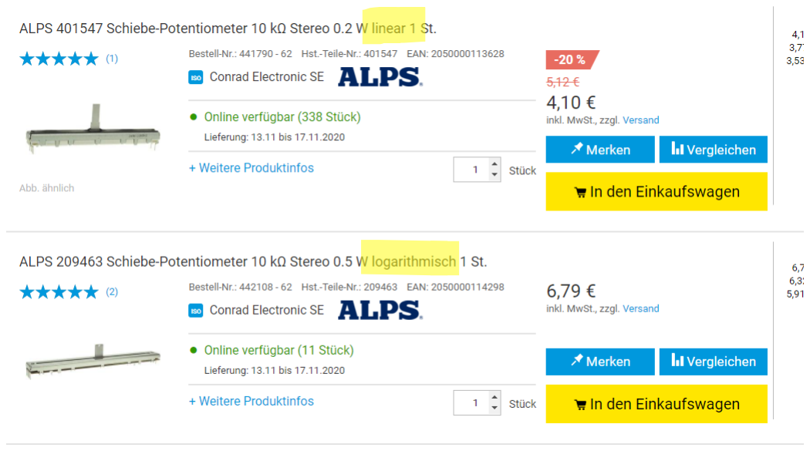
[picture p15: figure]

Abbildung 10: Screenshot aus einem Internet-Shop

Technische Schiebewiderstände haben drei Anschlüsse. Ein Anschluss ist mit dem beweglichen Abgriff verbunden. Auch mit den beiden Enden der Widerstandsbahn bzw. der Drahtwicklung hat je ein Anschluss Kontakt. Zur Messung des eingestellten Widerstandes verbindet man ein Ohmmeter mit dem Abgriff und mit einem der beiden Enden (siehe Abbildung 11).

Abbildung 11: Technologieschema

3.4.2 Der Versuchsstand
Für die Schiebewiderstand-Versuche im Labor stehen drei Varianten zur Verfügung (siehe auch Abbildung 8):
Typ | SCHIEBEWEG | WIDERSTANDSWERT
„großer“ Schiebewiderstand (Bild links) | ca. 30cm | 300Ohm
„kleiner“ Schiebewiderstand (Bild Mitte) | ca. 6cm | 10kOhm
Schiebewiderstand-In-A-Box (Bild rechts) | ca. 10cm | 10kOhm

Wir behaupten an dieser Stelle einfach mal, dass es sich in allen Fällen um einen linearen Widerstand handelt. Der Widerstand soll also proportional zur Schieberstellung sein. Der Schiebewiderstand sei also ein Beispiel für ein Proportionalglied.

Neben den Widerständen erhalten Sie Kabel für alle erforderlichen elektrischen Verbindungen und ein Multimeter mit der Möglichkeit zur Widerstandsmessung.

Ω

Widerstandsbahn

Ohmmeter

R = KP ∙ x

Schieberposition x

3.4.3 Versuchsdurchführung
Wie oben bereits erklärt, entstehen keine zeitlichen Verzögerungen zwischen dem Eingang „Schieberstellung“ und dem Ausgang „Widerstand“. Auf die Ermittlung von Sprungantworten kann deshalb verzichtet werden. Es soll aber die Kennlinie des Widerstandes bestimmt werden, um die in der Einleitung aufgestellte Behauptung „proportional“ zu überprüfen. Gehen Sie bei der Durchführung des Versuches wie folgt vor:
- Schließen Sie das Multimeter korrekt an und stellen Sie einen passenden Widerstandsmessbereich ein (falls das Multimeter kein Auto-Range unterstützt). Nutzen Sie dazu Abbildung 12 und Abbildung
13. Beim „Schiebewiderstand-in-a-Box“ müssen Sie zunächst eine kleine Knobelaufgabe lösen: Im Gehäuse sind sowohl ein linearer als auch ein logarithmischer Schiebewiderstand montiert Aus dem Gehäuse führen vier nicht gekennzeichnete Kabel. Diese sind entweder am unteren Ende der Widerstandsbahn oder am Schleifer eines Schiebewiderstandes angebracht. Finden Sie mit Hilfe des Multimeters heraus, welche beiden Kabel zum logarithmischen Schiebewiderstand gehören und verwenden Sie diesen für die weitere Aufgabe!

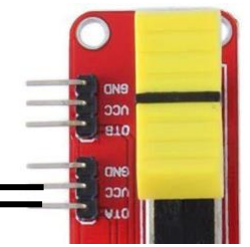
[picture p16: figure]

Abbildung 12: Anschluss des „kleinen“ Schiebewiderstandes

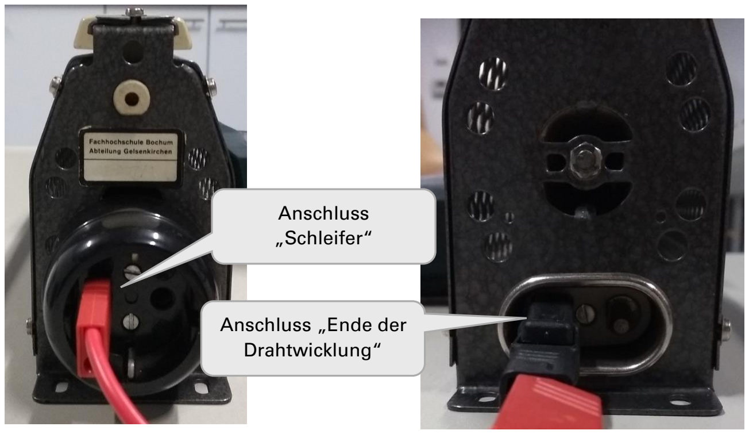
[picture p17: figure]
Anschluss „Schleifer“; Anschluss „Ende der Drahtwicklung“

Abbildung 13: Anschluss des "großen" Schiebewiderstandes

- Finden Sie heraus, an welchem Ende der Schiebewiderstand einen elektrischen Widerstand von etwa 0 Ohm hat.

Ω

- Nutzen Sie jeweils die Skala auf dem Schiebewiderstand, um den Schieber in sinnvollen Schritten zu bewegen. Die Position wird als x bezeichnet. Lesen Sie jeweils den Widerstandswert R ab und tragen ihn in eine vorbereitete Tabelle ein.

3.4.4 Versuchsauswertung
Erstellen Sie (auf Papier, nicht mit Excel! → Klausurübung!) ein Diagramm für die Funktion R(x). Bereiten Sie dieses Diagramm zu Hause vor.

Beim Betrachten des Diagramms fällt Ihnen auf, dass keine Proportionalität vorliegt.

Für Gruppen mit dem „großen“ Schiebewiderstand

Linearisieren Sie die Kennlinie des großen Schiebewiderstandes in den Arbeitspunkten x0 = 5 cm und x0 = 21 cm und bestimmen Sie den Übertragungsbeiwert KP in den beiden Arbeitspunkten.

Drehen Sie den Draht-Schiebewiderstand um und betrachten Sie seine Drahtwicklung. Durch welche konstruktive Maßnahme wird das Verhalten der aufgenommenen Kennlinie bewirkt?

Für Gruppen mit dem „kleinen“ Schiebewiderstand

Linearisieren Sie die Kennlinie des logarithmischen Schiebewiderstandes in den Arbeitspunkten x0 = 2 cm und x0 = 4 cm und bestimmen Sie den Übertragungsbeiwert KP in den beiden Arbeitspunkten.

Wenn Sie sich den „kleinen“ Schiebewiderstand genauer anschauen, dann sehen sie zwei gleichartige Anschlussgruppen („OTA“ mit GND und VCC sowie „OTB“ mit GND und VCC). Was könnte es damit auf sich haben? Denken Sie insbesondere an die Anwendungsfälle in der Audiotechnik.

Für Gruppen mit dem „Schiebewiderstand-in-a-Box“

LinearisierenSie die Kennlinie des kleinenSchiebewiderstandes in den Arbeitspunkten x0 = 3 cm und x0 = 7 cm und bestimmen Sie den Übertragungsbeiwert KP in den beiden Arbeitspunkten.

3.4.5 Abgaben
- R(x)-Diagramm
- Für Gruppen mit dem „großen“ Widerstand: Aussage zur Konstruktion, Ergebnisse der Linearisierung
- Für Gruppen mit dem „kleinen“ Widerstand: Aussage zu den beiden gleichartigen Anschlussgruppen, Ergebnisse der Linearisierung
- Für Gruppen mit dem „Schiebewiderstand-in-a-Box“: Erklärung, wie Sie die zum logarithmischen Widerstand zugehörigen Kabel herausgefunden habt

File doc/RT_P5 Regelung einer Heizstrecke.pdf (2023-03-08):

Prof. Dr.-Ing. Klaus M. Liebler
Gebäudeautomation und Anlagensteuerungstechnik Fachbereich Maschinenbau, Umwelt- und Gebäudetechnik

## Praktikum Regelungstechnik

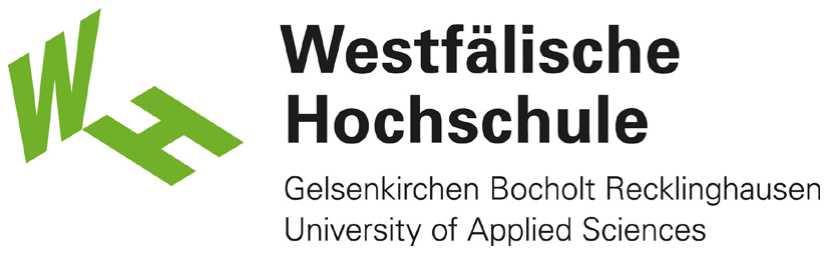
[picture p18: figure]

# Termin 5: Regelung einer Heizstrecke

Version 20210113

Bitte senden Sie Verbesserungsempfehlungen jederzeit an den Autor.

Klaus Liebler
klaus.liebler@w-hs.de
Raum B2.3.09
Tel: +49 (209) 9596-152

Andreas Recktenwald
andreas.recktenwald@w-hs.de Raum B4.3.3
Tel: +49 (209) 9596-122

Fachbereich Maschinenbau, Umwelt- und Gebäudetechnik Westfälische Hochschule
Neidenburger Str. 43
45897 Gelsenkirchen
www.w-hs.de

© Westfälische Hochschule. Alle Aufgaben dürfen ausschließlich zu Lehr- und Lernzwecken im Rahmen der oben genannten Lehrveranstaltung verwendet werden.

### Inhalt

1 | Lernziele | 1
2 | Vorbereitung | 2
3 | Konzepte und Komponenten | 2
3.1 | Das Experimentiersystem lab@home | 2
3.2 | Einstellregeln nach Chien, Hrones und Reswick | 2
4 | Versuchsdurchführung | 2
4.1 | Sprungantwortversuch zur Charakterisierung der Regelstrecke durchführen | 2
4.2 | Reglerparameter bestimmen | 4
4.3 | <Ihr Name> vs. PID | 2
4.4 | Führungs- und Störgrößenverhalten des Reglers | 4
4.5 | Auswertung | 6
5 | Auswerteformular „Regelung einer Heizstrecke“ | 7
5.1 | Auswertung für Kapitel 4.4 | 7

## 1 Lernziele

- Die Studierenden können reale PID- und Zweipunktregler parametrieren und testen.

Prof. Dr.-Ing Klaus M. Liebler

- Die Studierenden lernen die besondere Bedeutung praxisrelevanter Herausforderungen im Bereich der Regelungstechnik kennen.
- Die Studierenden können mit Hilfe der Simulation Gütemaße qualitativ und quantitativ bestimmen und Aussagen über die Güte der Regelung treffen

## 2 Vorbereitung

- Lesen Sie sich diese Versuchsbeschreibung gründlich durch.
- Wiederholen Sie die relevanten Inhalte der Vorlesung.

Stichwörter:

Heuristiken zur Reglereinstellung, Chien-Hrones-Reswick

## 3 Konzepte und Komponenten

### 3.1 Das Experimentiersystem lab@home

Bei diesem Versuch arbeiten Sie wieder mit dem Experimentiersystem lab@home, das Sie aus dem zweiten Praktikum noch kennen. Lesen Sie sich dort nochmals die Beschreibung des Experimentiertaufbaus durch.

### 3.2 Einstellregeln nach Chien, Hrones und Reswick

Die Verfahren rund um die Einstellregeln nach Chien, Hrones und Reswick kennen Sie noch aus dem vierten Praktikum. Lesen Sie sich im Bedarfsfall die entsprechenden Kapitel aus der Praktikumsbeschreibung durch.

## 4 Versuchsdurchführung

### 4.1 <Ihr Name> vs. PID 😊😊

Nehmen Sie die Herausforderung an und stellen Sie Ihr regelungstechnisches Gefühl unter Beweis!

Öffnen Sie die WebUI von lab@home (siehe Abbildung 1), klicken Sie im Menü links auf „Heater Experiment“ (1) und wählen Sie oben den Betriebsmodus „Open Loop“ (2). Starten Sie die Aufzeichnung (3).

Belassen Sie die Störgröße „Fan Power“ (4) zunächst bei 0 und stellen Sie die Stellgröße „Heater Power“
(5) so ein, dass Sie möglichst schnell und ohne Überschwingen eine „Actual Temperature“ von 60°C (6) erreichen. Wenn Sie dies geschafft haben, ändern Sie „Fan Power“ (4) auf 30% und versuchen Sie, die „Actual Temperature“ (6) auf 60°C zurückzuführen. Sichern Sie Ihre Ergebnisse und unterstützen Sie die Abkühlung des Heizwiderstandes mit einer „Fan Power“ (4) von 100%.

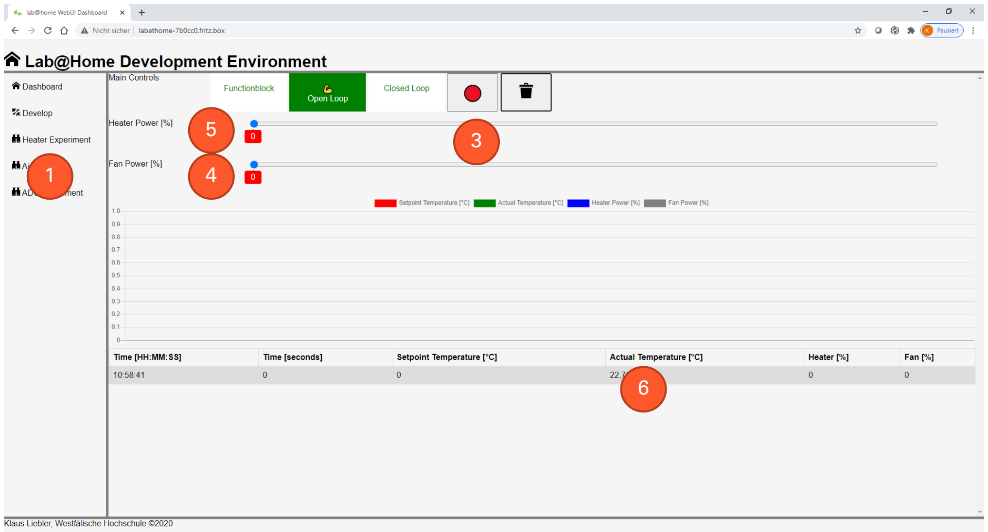
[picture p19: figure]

Abbildung 1: Das lab@home-Experimentiersystem (Open Loop)

### 4.2 Sprungantwortversuch zur Charakterisierung der Regelstrecke durchführen

Im Rahmen des zweiten Praktikumsversuches haben wir die Regelstrecke „Heizwiderstand“ charakterisiert und dabei das folgende Ergebnis gewonnen:

EIGENSCHAFT | WERT
KP | 1,9K/%
TE | 20s
TB | 350s
Tabelle 1: Parameter der Regelstrecke
| • Zahlenwert des Schwierigkeitsgrades S der Strecke
| • Verbale Beurteilung der Regelbarkeit der Strecke.

### 4.3 Reglerparameter mit Hilfe von Chien-Hrones-Reswick bestimmen

Bestimmen Sie mit Hilfe der folgenden Tabelle die Parameter für

- PID-Regler
- Regelverhalten mit 20% Überschwingen
- Variante a) Optimiert für gutes Störverhalten
- Variante b) Optimiert für gutes Führungsverhalten
Es gilt die Abkürzung LL = TTbb

# Te⋅KP,S

TYP | GRÖßE | APERIODISCHER REGELVERLAUF | REGELVERLAUF MIT 20% ÜBERSCHWINGEN
| | Störung | Führung | Störung | Führung
P | KP,R | 0,3·L | 0,3·L | 0,7·L | 0,7·L
PI | KP,R | 0,6·L | 0,35·L | 0,7·L | 0,6·L
| Tn | 4,0·Te | 1,2·Tb | 2,3·Te | 1,0·Tb
PID | KP,R | 0,95·L | 0,6·L | 1,2·L | 0,95·L
| Tn | 2,4·Te | 1,0·Tb | 2,0·Te | 1,35·Tb
| Tv | 0,42·Te | 0,50·Te | 0,42·Te | 0,47·Te
Tabelle 2: Einstellregeln nach Chien, Hrones und Reswick
- Werte für KP,R, TN und TV für Reglervariante (a) und (b)

### 4.4 Führungs- und Störgrößenverhalten des Reglers

Nun ist der PID-Regler dran. Öffnen Sie die WebUI von lab@home (siehe Abbildung 2), klicken Sie im Menü links auf „Heater Experiment“ (1) und wählen Sie oben den Betriebsmodus „Closed Loop“ (2).

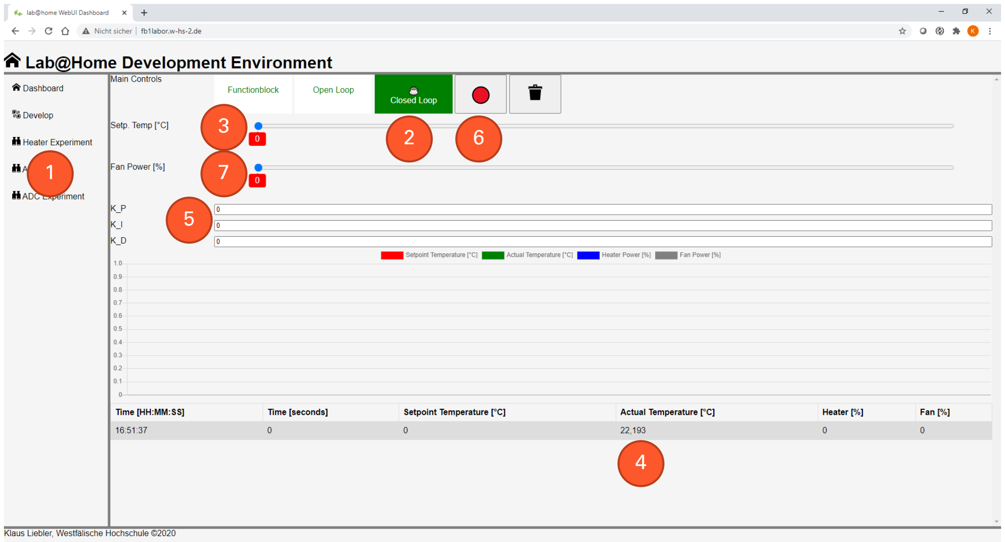
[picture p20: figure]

Abbildung 2: Das lab@home-Experimentiersystem (Closed Loop)

Führen Sie die folgenden Schritte zunächst mit Reglervariante (a) und dann nach einer Abkühlpause auch für Reglervariante (b) durch.

1. Stellen Sie die Führungsgröße „Setp. Temperature) (3) auf die aktuelle Temperatur des Heizwiderstandes (4) ein.
2. Stellen Sie dann die Reglerparameter (5) gemäß Variante (a) bzw. (b) ein.

Es gilt: KKII = KKPP/TTNN und KKDD = KKPP ∙ TTVV (oder auch umgekehrt TTNN = KKPP/KKII und TTVV = KKDD/KKPP)

3. Starten Sie die Aufzeichnung (6).
4. Verändern Sie die Führungsgröße (3) sprungartig auf 60°C.

Warten Sie nun, bis die Regelgröße zumindest näherungsweise den Beharrungsendwert erreicht hat. Sie sehen nun das Führungsverhalten des Reglers.

5. Stellen Sie die Störgröße „Fan Power“ sprungartig auf 30% (7)

Warten Sie nun, bis die Regelgröße zumindest näherungsweise den Beharrungsendwert erreicht hat. Sie sehen nun das Störgrößenverhalten des Reglers.

6. Beenden Sie die Aufzeichnung und kopieren Sie die Tabelle zur weiteren Auswertung in Excel.
7. Ändern Sie den Betriebsmodus auf „Open Loop“. Stellen Sie eine Heizleistung von 0% und zum beschleunigten Abkühlen eine Ventilatorleistung von 100% ein.

### 4.5 Auswertung

Bestimmen Sie für die beiden Reglervarianten (a) und (b) für die Zeit nach dem Führungssprung und die Zeit nach dem Störgrößensprung die folgenden Regelgüte-Parameter. Gehen Sie von einem Toleranzbereich von 2 ∙ ∆xxss = 2°CC aus.

SYMBOL | BEDEUTUNG
∆XX∞ | Abweichung im Beharrungszustand
xxmm | Überschwingweite
TTcccc | Anregelzeit
TTcccc | Ausregelzeit

Tabelle 3: Gütemaße

Prüfen Sie, ob die beiden Reglervarianten tatsächlich so wie vorgesehen arbeiten und diskutieren Sie die Ergebnisse. Vergleichen Sie Ihre „Reglerperformance“ mit der des Reglers.

Hinweis: Möglicherweise können nicht bei jedem Reglertyp alle Parameter bestimmt werden.

## 5 Auswerteformular „Regelung einer Heizstrecke“

### NAME

MATRIKELNUMMER

### DATUM

### 5.1 Auswertung für Kapitel 4.4

Bezeichnung ∆XX∞ | Reglervariante a | Reglervariante b | Menschlicher Regler
Führungs-sprung | Störgrößen-sprung | Führungs-sprung | Störgrößen-sprung | Führungs-sprung | Störgrößen-sprung

xxmm

TTcccc

TTcccc

Diskussion

Wie gut war
Ihre eigene
„Reglerperformance“ im
Vergleich?

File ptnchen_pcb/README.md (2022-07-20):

# smopla_PTN2 - "Das kleine Peteh Ennchen"

Der kleine Bruder von lab@home. Ermöglicht das Experimentieren mit PT1...PTn-Gliedern, die intern als RC-Kombination (entkoppelt über Operationsverstärker) ausgeführt sind.
Features:
- Drei hintereinander geschaltete RC-Glieder, die bekanntlich PT1-Verhalten aufweisen; bilden eine Regelstrecke
- WIFI-fähiger Microcontroller (ESP32)
- Webbasierte Schnittstelle
- bald: Schnittstelle zu WinFACT Boris über WiFi
- Anregung über mechanischen Schalter oder softwaregesteurert über den Microcontroller
- Jedes PT1-Glied kann mit einstellbarer Intensität gestört werden
- Technisch: Anregungsspannung und Spannungen am Ausgang der RC-Glieder über Laborstecker herausgeführt und auf Analog-Digital-Wandler geführt
- Fachlich: Spannungen sind über externe Messinstrumente messbar oder stehen auf der Weboberfläche zur Verfügung oder stehen in einem BORIS-Funktionsbaustein zur Verfügung
- Softwareseitig kann der Regelkreis geöffnet oder geschlossen werden. Es stehen verschiedene Reglertypen und Parametersets zur Verfügung
- Die Verstärker zur Entkopplung der PT1-Glieder lassen sich mechanisch aktivieren und deaktivieren (dann keine Rückkopplungsfreiheit)
- Farbige LEDs zeigen den Zustand des Gesamtsystems und der einzelnen PT1-Glieder an
- Spannungsversorgung, Programmierung und bei Bedarf auch Kommunikation über USB-C

Ein Bild der Baugruppe sagt mehr, als tausend Worte

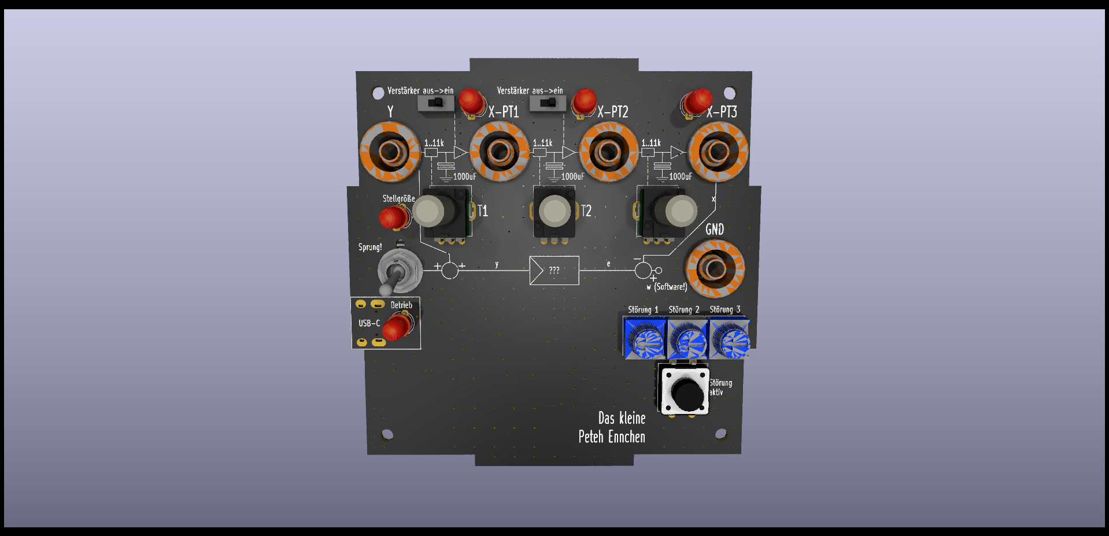
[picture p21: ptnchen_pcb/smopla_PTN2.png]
Rendering


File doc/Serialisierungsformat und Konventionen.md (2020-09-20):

Alle Variablen im System werden über ihren Typ (bool, s32, f32, color, string) und ihre Adresse - ein u32 - identifiziert

Für Bools und Ints gilt
0x0000_0000 bis 0x0000_FFFF: Konstanten mit dem Jeweiligen Wert
0x0001_0000 bis 0x0001_FFFF: Hardware-Inputs 
0x0010_0000 bis 0x0010_FFFF: Hardware-Outputs

0xFFFF_0000 bis 0xFFFF_FFFF: Normale Zwischenvariablen
HIer gilt:
//Unbeschaltete Outputs schreiben in Offset 0. 
//Unbeschaltete Inputs lesen vom Offset 1
//Echte Speicheradressen gibt es dann ab Offset 2

Große Frage ist: Wie schlau und auf das Board angepasst ist die Webapplikation? --> Am besten gar nicht angepasst! 

Die Webapplikation weiß nichts von den Speicheradressen auf dem Board
Der Datensatz erhält 
Version der Datenstruktur u32 (vorerst immer 0)
timestamp u64
KEINE maxIndizes - das kann das Board problemlos selbst rechnen
Für jeden Operator zunächst den TypIndex (u32) und den globalen Index (u32) des Browsers. Dann Adressen u32 für Input und dann Adressen u32 für Output
Danach mögliche KOnfigurationsparameter

Problem: Es muss absolut sicher gestellt sein, dass sind die Länge der Konfiguration eines TypIndex niemals ändert!!!

Der Operator muss sich selbst in ein u32-Array serialisieren können, sofern er die AdressMaps bekommts

Variablen werden FÜR JEDEN DATENTYP UNABHÄNGIG mit einer 32bit ID identifiziert
Für Bool gilt
- Index 0 liefert immer False (dies ist auch der Standardwert für "nicht angeschlossen)
- Index 1 liefert immer True
- Index 2...1023 ist Hardware-Input
- Index 1024...2047 ist Hardware-Output
- Index 2048...3071 ist Kommunikations-Input
- Index 3072...4095 ist Kommunikations-Output
- Variablen mit Index 16384..32767 sind "Zwischenvariablen"
- Variablen mit Index >=32768 sind reserviert (ggf für Retained?)
Für Integer gilt
- Index 0 liefert immer 0
- Index 1 liefert immer 1
- tbc

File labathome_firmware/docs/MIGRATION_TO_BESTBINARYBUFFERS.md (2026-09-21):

# Migration auf BestBinaryBuffers + C#-Build-System

**Status: umgesetzt (September 2026)** -- Plugins, devicemanager, Web-UI (lokale Kopien von Flowchart/Heater-Experiment) und der C#-Builder (`builder/`) sind migriert; generierte Dateien liegen in `generated/`. Der folgende Text beschreibt den urspruenglichen Plan.

(Alter Status: noch nicht begonnen.) Dieses Dokument beschreibt, was in `sensact_firmware`
bereits passiert ist, warum das hier relevant ist, und was konkret zu tun ist, um
`labathome_firmware` auf denselben Stand zu bringen.

## Warum das jetzt dringend ist

`labathome_firmware` bindet `espidf-component-webmanager` als geteilte Komponente
ein (`CMakeLists.txt`: `EXTRA_COMPONENT_DIRS "../../espidf-component-webmanager"`,
zeigt auf `C:\repos\espidf-component-webmanager`). Dieselbe Komponente wird auch von
`sensact_firmware` genutzt. Dort wurde sie im August 2026 komplett von Flatbuffers auf
[BestBinaryBuffers](https://github.com/klaus-liebler/best_binary_buffers) umgestellt
(eigenes Repo, Schema als annotierter C#-Code statt `.fbs`) -- **inklusive einer
Breaking Change am Plugin-Interface selbst**. Das heisst: der aktuelle Checkout von
`espidf-component-webmanager` kompiliert mit `labathome_firmware`s Plugins (Stand
dieses Dokuments) **nicht mehr**.

Ausserdem: die generierten Flatbuffers-Header, auf die `labathome_firmware`s Plugins
sich beziehen (`generated/flatbuffers_cpp/ns03functionblock_generated.h`,
`ns04heaterexperiment_generated.h`, sowie client-seitig `@generated/flatbuffers_ts`),
wurden im Zuge dieser Migration aus `C:\repos\generated\` **geloescht** (waren in
`sensact_firmware` bereits vollstaendig ungenutzt). Ein Build von `labathome_firmware`
schlaegt dadurch aktuell schon beim Includieren fehl, nicht erst beim Linken gegen die
neue Interface-Signatur.

## Was sich am Plugin-Interface geaendert hat

`espidf-component-webmanager/cpp/webmanager_interfaces.hh`:

```diff
- virtual esp_err_t WrapAndSendAsync(uint32_t namespaceId, flatbuffers::FlatBufferBuilder& b) = 0;
+ virtual esp_err_t SendRawAsync(const uint8_t* data, size_t len) = 0;
```

```diff
- virtual eMessageReceiverResult ProvideWebsocketMessage(iWebmanagerCallback *callback,
-     httpd_req_t *req, httpd_ws_frame_t *ws_pkt, uint32_t ns, uint8_t *buf) = 0;
+ virtual eMessageReceiverResult ProvideWebsocketMessage(iWebmanagerCallback *callback,
+     httpd_req_t *req, httpd_ws_frame_t *ws_pkt, uint16_t namespaceId, uint16_t messageTypeId,
+     const uint8_t *frame, size_t frameLen) = 0;
```

`frame` zeigt jetzt auf den **kompletten** Frame inkl. 4-Byte-Kopf (2x `uint16`:
`namespaceId`, `messageTypeId`) -- kein Vorab-Slicing mehr durch den Dispatcher. Die
generierten `WsProtocol::<namespace>::<Message>::Decode(frame, frameLen, out)`-
Funktionen ueberspringen die ersten 4 Bytes selbst.

## Konkret zu aendernde Dateien in diesem Repo

- **`main/webmanager_plugins/functionblock_plugin.hh`** und
  **`heaterexperiment_plugin.hh`**: `ProvideWebsocketMessage`-Signatur anpassen (s.o.),
  `#include "flatbuffers/flatbuffers.h"` + `#include "../generated/flatbuffers_cpp/..."`
  durch `#include "wsprotocol_cpp/ws_protocol.hh"` ersetzen,
  `flatbuffers::GetRoot<...>`/`request_type()`-Switch durch
  `if (namespaceId != WsProtocol::<ns>::NAMESPACE_ID) return NOT_FOR_ME;` +
  `switch (messageTypeId)` gegen die generierten `TYPE_ID`-Konstanten ersetzen,
  `callback->WrapAndSendAsync(ns, b)` durch `WsProtocol::<ns>::<Response>::Payload`
  befuellen + `Encode(...)` in einen Stack-Puffer + `callback->SendRawAsync(buf, len)`
  ersetzen. Die Schemas fuer beide Namespaces existieren **bereits** (wurden im Zuge
  der sensact-Migration mit generiert, auch wenn sensact selbst keinen Server dafuer
  hat): `C:\repos\espidf-component-webmanager\ws-protocol\functionblock.cs` /
  `heaterexperiment.cs`. `RequestFbdRun`/`ResponseFbdRun`/`RequestDebugData`/
  `ResponseDebugData` bzw. `RequestHeater`/`ResponseHeater` sind 1:1 gegen die
  bisherigen Flatbuffers-Felder benannt -- die Migration ist reines Feld-fuer-Feld-
  Nachvollziehen, keine Schema-Neugestaltung noetig. Referenzimplementierung fuer genau
  dieses Muster (Request/Response, kein Array/Union): `systeminfo_plugin.hh` in
  `espidf-component-webmanager/cpp/webmanager_plugins/` (bereits migriert).
  `ResponseDebugData`s `Bools`/`Integers`/`Floats`/`Colors`-Arrays sind im neuen Schema
  `UniformPackedArrayField`s aus Einzelfeld-Wrapper-Structs (`BoolValue{Value:bool}`
  usw., s. Kommentar in `functionblock.cs`) -- Referenz fuer das Codegen-Muster:
  `AppendResponseSystemDataPartitionsPartitionInfoElement` in `systeminfo_plugin.hh`
  (analoges Array-Feld, andere Elementstruktur).
- **`main/main.cc`**: `webmanager::M::GetSingleton()->Begin(...)`-Aufruf pruefen -- die
  Begin-Signatur hat in sensact_firmware neue optionale Parameter bekommen
  (`apFallbackTimeout_us`, `auth_username`/`auth_password`), s.
  `C:\repos\sensact\firmware\sensact_firmware\main\main.cc` als Referenz.
- **`web/`**: `@klaus-liebler/web-components` importiert(e) `Flowchart.ts`,
  `develop_cfc_controller.ts` (functionblock) und `heater_experiment_controller.ts`
  (heaterexperiment) aus `@generated/flatbuffers_ts/functionblock` bzw.
  `/heaterexperiment`. **Diese drei Dateien wurden im Zuge dieser Aufraeumaktion aus
  `web-components` entfernt** (waren nur fuer labathome_firmware relevant, s. dortiges
  `docs/plan_v2/03-wifimanager-review.md`, Abschnitt "ws-protocol-Migration" ->
  "Uebergangsregel"). Fuer `labathome_firmware`s eigenen `web/`-Client heisst das: die
  alten Dateiversionen aus der Git-Historie von `npm-packages`
  (`@klaus-liebler/web-components`) holen (letzter Commit, der sie noch enthielt, vor
  ihrer Loeschung) und als **lokale** Kopien in `labathome_firmware/web/` uebernehmen
  (nicht mehr aus dem geteilten Paket importieren), dann auf
  `@generated/wsprotocol_ts/ws-protocol.ts` umstellen -- Transport-Interface
  (`IMessageListener`/`IAppManagement.SendFrame`/`RegisterNamespace`) in
  `web-components/typescript/utils/interfaces.ts` ist bereits auf den neuen,
  einheitlichen Mechanismus umgestellt (kein Flatbuffers-Praefix-Bau mehr durch
  `AppController` selbst).

## Empfehlung: C#-Build-System uebernehmen

Neben der reinen Protokoll-Migration lohnt es sich, gleich den alten Node/Gulp-
Orchestrator (`builder/gulpfile.ts`) durch das neue C#-Pendant zu ersetzen -- in
`sensact_firmware` als `builder/` (vormals `builder_cs/`, dort umbenannt sobald der
alte TS-Orchestrator obsolet war). Vorteile/Vorgehen: s.
`C:\repos\sensact\firmware\sensact_firmware\docs\plan_v2\02-builder-migration-csharp.md`
fuer die Migrationsentscheidung, `builder/Program.cs` fuer die Phasen-CLI
(`GenerateWsProtocolFiles`, `BuildFirmware`, `FlashFirmware`, ...),
`builder/Phases/GenerateWsProtocolFiles.cs` fuer die Codegen-Phase, die auch hier
direkt wiederverwendbar sein sollte (liest `*.cs`-Schema-Dateien aus einem oder
mehreren `ws-protocol/`-Verzeichnissen -- fuer labathome waere das vermutlich
`labathome_firmware/ws-protocol/` + weiterhin `espidf-component-webmanager/ws-protocol/`
fuer die geteilten Namespaces).

## Wo generierte Dateien jetzt liegen

`sensact_firmware` schreibt seine generierten Dateien projektlokal nach
`sensact_firmware/generated/` (nicht mehr nach `C:\repos\generated\`, s. dortiges
`builder/Paths.cs`). `labathome_firmware`s `CMakeLists.txt` (`GENERATED_DIR`) und
`web/package.json` (`file:`-Abhaengigkeiten auf `@generated/...`) zeigen aktuell noch
auf `C:\repos\generated\` -- das existiert vorerst fuer die von `labathome_firmware`
noch benoetigten Teile weiter (`cmake/config.json`, `web/index.compressed.br`), sollte
aber im Zuge dieser Migration ebenfalls auf einen projektlokalen
`labathome_firmware/generated/`-Ordner umgestellt werden (gleiches Muster wie in
`sensact_firmware`).

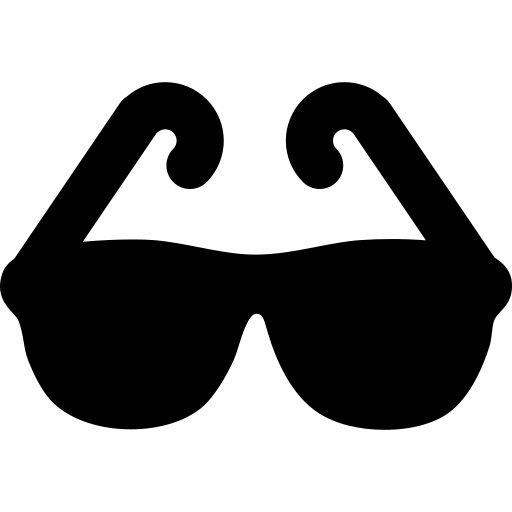
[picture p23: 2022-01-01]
labathome_pcb/googles.png

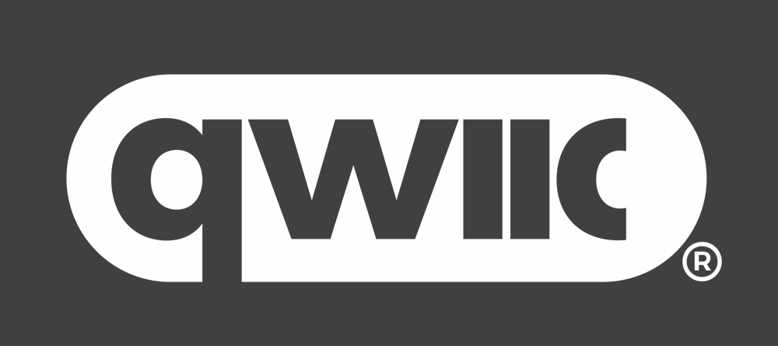
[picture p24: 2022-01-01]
labathome_pcb/Qwiic-registered-white.png

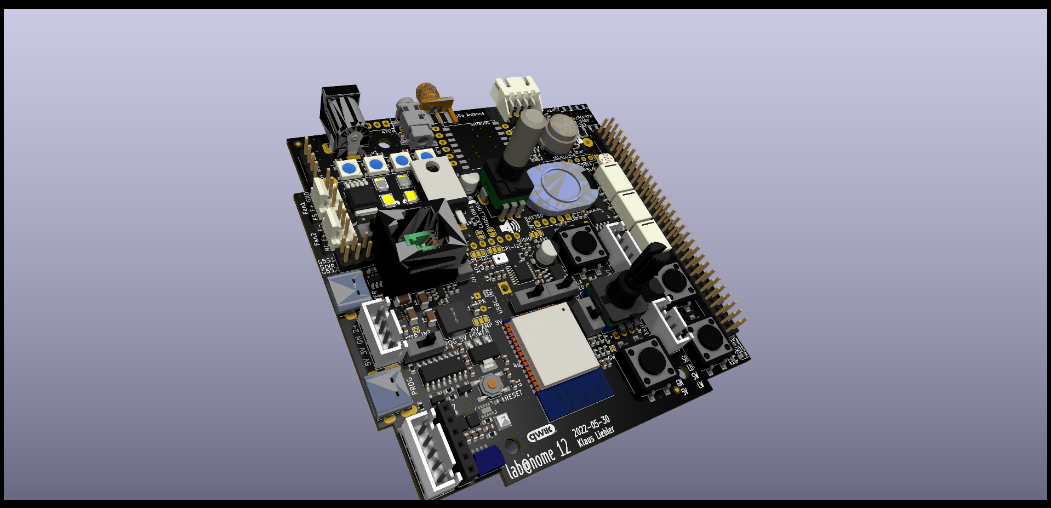
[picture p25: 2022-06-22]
labathome_pcb/pcbV10.png

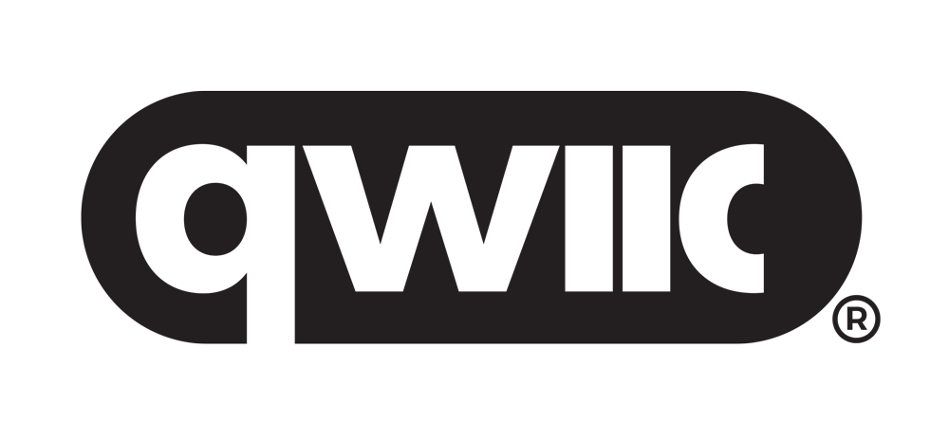
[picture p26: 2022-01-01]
labathome_pcb/Qwiic-registered-black.png

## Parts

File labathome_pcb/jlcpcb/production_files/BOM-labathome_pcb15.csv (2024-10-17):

Comment | Designator | Footprint | LCSC
600R | FB1,FB2 | L_0603_1608Metric | C1002
1k | R12,R29,R30,R34,R35,R42,R5,R6,R69,R71,R74,R8 | R_0402_1005Metric | C11702
SN65HVD230 | U7 | SOIC-8_3.9x4.9mm_Pitch1.27mm_handsolder | C12084
HTR ON | D14,D19 | LED_1206_3216Metric_ReverseMount | C125107
u1/16V | C51,C52,C63,C64,C79,C81 | C_0603_1608Metric | C14663
10n/35V | C38 | C_0402_1005Metric | C15195
POWER | J13,J29,J5 | USB_C_Receptacle_HRO_TYPE-C-31-M-12_IMPROVED | C165948
1u | L1 | L_0630 | C167216
10u | L4 | L_0630 | C167223
10R | R13,R15,R78 | R_1206_3216Metric | C17903
1N5819WS | D13,D20 | D_SOD-323 | C191023
TPS54202DDC | U27 | SOT-23-6_Handsoldering | C191884
BC817 | Q1,Q4 | SOT-23 | C20526
WHITE | D10,D11,D12,D8,D9 | LED_PLCC_2835_Handsoldering | C210325
1R | R28,R3,R47,R7 | R_0603_1608Metric | C22936
4u7 | C12,C13,C14,C15,C21,C22,C36,C41,C43,C61 | C_0402_1005Metric | C23733
k22 | R1,R40,R66,R70,R9 | R_0402_1005Metric | C25091
56p | C82 | C_0402_1005Metric | C258506
2k2 | R10,R14,R16,R24 | R_0402_1005Metric | C25879
3k3 | R43,R44,R48,R73 | R_0402_1005Metric | C25890
M1 | R25,R53,R54,R59 | R_0201_0603Metric | C270364
5k1 | R18,R19 | R_0201_0603Metric | C274341
AHT20 | U12 | AHT21 | C2757850
MJD31C | Q3 | TO-252-2 | C27596
SRV05-4 | U8 | SOT-23-6 | C2836319
ESP32-S3-WROOM-1 | U4 | ESP32-S3-WROOM-1 | C2913204
IRLML6344 | Q2,Q5,Q6 | SOT-23 | C2938367
r1 | R38 | R_2512_6332Metric | C2960832
TPS2116DRL | U18 | SOT-583-8 | C3235557
PROG_STM | J36 | PinSocket_2x06_P2.54mm_Vertical_SMD | C3294464
10p | C10,C8,C9 | C_0402_1005Metric | C32949
AUX OUT | J14,J16,J3 | PJ-327A | C381135
Micro_SD_Card_Det1 | J17 | microSD push | C393941
PROG ESP | J6 | PinHeader_2x03_P1.27mm_Vertical_SMD_handsolder | C3975186
STM32G431R8Tx | U5 | LQFP-64_10x10mm_P0.5mm | C431633
G6K-2 | K1 | Relay_DPDT_Omron_G6K-2F-Y | C47190
10k | R11,R17,R2,R21,R22,R26,R27,R31,R36,R37,R39,R4,R41,R45,R50,R51,R55,R56,R57,R58,R60,R61,R62,R63,R64,R65,R67,R68,R72,R75 | R_0201_0603Metric | C473048
100u | C39 | CP_Elec_6.3x5.4 | C4747966
IP5306_I2C | U2 | HSOP-8-1EP_3.9x4.9mm_P1.27mm_EP2.3x2.3mm_ThermalVias | C488349
1u | C37,C42,C44,C59 | C_0402_1005Metric | C52923
Reset | SW1 | Button_2x4x3,5_handsolder | C5373430
RGB2 | D15,D16,D17,D21 | SK6812MINI-E_REV | C5378731
POWER | SW5,SW7,SW8 | SW_Push_1P1T_NO_6x6mm_H6.5mm_Reverse | C541957
22u | C28,C29,C30,C31,C56,C6,C7,C83,C84 | C_0603_1608Metric | C59461
10u | C1,C4,C80 | C_0805_2012Metric | C6119888
AMS1117 | U11 | SOT-223-3_TabPin2 | C6186
MAX3485 | U1 | SOIC-8_3.9x4.9mm_Pitch1.27mm_handsolder | C668205
1u | C16,C17,C20,C23,C24,C62 | CP_EIA-3216-10_Kemet-I | C7174
u1 | C11,C2,C25,C26,C27,C3,C32,C33,C34,C35,C40,C45,C46,C47,C48,C49,C5,C50,C53,C54,C55,C57,C60,C65,C66 | C_0201_0603Metric | C76934
220u | C18,C19 | CP_Elec_6.3x5.4 | C88673
NAU8822 | U10 | QFN-32-1EP_5x5mm_P0.5mm_EP3.6x3.6mm_ThermalVias | C914209
DRV8313 | U3 | HTSSOP-28-1EP_4.4x9.7mm_P0.65mm_EP2.85x5.4mm_ThermalVias | C92482
LM358 | U16 | SOIC-8_3.9x4.9mm_P1.27mm | C9418
LSM6DS3 | U9 | LGA-14_3x2.5mm_P0.5mm_LayoutBorder3x4y | C967633
Servos | J26 | PinHeader_2x09_P2.54mm_Horizontal_SMD

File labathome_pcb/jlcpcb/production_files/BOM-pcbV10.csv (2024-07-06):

Comment | Designator | Footprint | LCSC
100R | FB1 | L_0805_2012Metric | C1015
10u | C22,C27,C60 | C_1206_3216Metric | C13585
u1 | C10,C11,C12,C14,C15,C16,C18,C19,C20,C24,C25,C28,C29,C30,C31,C32,C33,C35,C37,C4,C40,C42,C44,C5,C51,C52,C54,C55,C6,C7 | C_0603_1608Metric | C14663
10n | C49 | C_0402_1005Metric | C15195
1u | C23,C3,C38,C9 | C_0603_1608Metric | C15849
2n2 | C53 | C_0603_1608Metric | C1604
QWIIC | J21 | JST_SH_SM04B-SRSS-TB_1x04-1MP_P1.00mm_Horizontal | C160404
n33 | C56,C57 | C_0603_1608Metric | C1664
PROG | J1,J8 | USB_C_Receptacle_HRO_TYPE-C-31-M-12_IMPROVED | C167321
10R | R32,R33 | R_1206_3216Metric | C17903
3k3 | R19 | R_1206_3216Metric | C17936
1u | C17,C58 | C_1206_3216Metric | C1848
4u7 | C1,C8 | C_0603_1608Metric | C19666
10u | C26,C39,C61 | C_0603_1608Metric | C19702
IRLML6344 | Q5,Q9 | SOT-23 | C20917
1k | R1,R11,R12,R14,R15,R17,R23,R26,R34,R36,R4,R44 | R_0603_1608Metric | C21190
k1 | R24,R25,R49 | R_0603_1608Metric | C22775
K12 | R13 | R_0603_1608Metric | C22787
13k | R45 | R_0603_1608Metric | C22797
1M | R54 | R_0603_1608Metric | C22935
1R | R40,R42 | R_0603_1608Metric | C22936
M22 | R43 | R_0603_1608Metric | C22961
4k7 | R21,R28,R5,R8 | R_0603_1608Metric | C23162
5k1 | R2,R3 | R_0603_1608Metric | C23186
68k | R46 | R_0603_1608Metric | C23231
k1 | R50 | R_0402_1005Metric | C25076
10k | R10 | R_0402_1005Metric | C25744
M22 | R48 | R_0402_1005Metric | C25767
10k | R16,R35,R37,R38,R51,R52,R6,R7 | R_0603_1608Metric | C25804
AHT21 | U3 | AHT21 | C2827328
WS2812B | D1,D15,D2,D3 | LED_WS2812B_PLCC4_5.0x5.0mm_P3.2mm | C2843785
AS4950 | U16 | SOIC-8-1EP_3.9x4.9mm_P1.27mm_EP2.29x3mm_ThermalVias | C2929412
22k | R20,R39,R53 | R_0603_1608Metric | C31850
RESET | SW12 | SW_SPST_TL3342 | C318884
PSM712 | D4 | SOT-23 | C32677
RY8310 | U9 | SOT-23-6 | C370876
4u7 | L2 | L_Abracon_ASPI-0630LR | C408447
2k2 | R22,R30 | R_0603_1608Metric | C4190
G6K-2 | K1,K2,K3 | Relay_DPDT_Omron_G6K-2F-Y | C425975
FUSB302BMPX | U11 | WQFN-14-1EP_2.5x2.5mm_P0.5mm_EP1.45x1.45mm | C442699
10n | C48,C50 | C_0603_1608Metric | C57112
22u | C2,C36,C47 | C_0603_1608Metric | C59461
AMS1117 | U1 | SOT-223-3_TabPin2 | C6186
ESP32-WROOM-32 | U2 | ESP32-WROOM-32 | C701342
WHITE | D10,D11,D12,D13,D14,D9 | LED_PLCC_2835 | C73545
LM358 | U10 | SOIC-8_3.9x4.9mm_P1.27mm | C7950
1N4007 | D5 | D_SOD-123 | C81598
HTR ON | D6,D7,D8 | LED_0805_2012Metric | C84256
CH340C | U4 | SOIC-16_3.9x9.9mm_P1.27mm | C84681
BC817 | Q1,Q2,Q4,Q6 | SOT-23 | C8512
SRV05 | U24 | SOT-23-6 | C85364
BTN BLUE | SW1,SW3,SW4,SW5 | SW_Push_1P1T_NO_CK_PTS125Sx43PSMTR | C879472
MAX3485 | U6 | SOIC-8_3.9x4.9mm_P1.27mm | C8963
MD8002A | U18 | SOIC-8_3.9x4.9mm_P1.27mm | C94625
MSM261D4030H1CPM | U26 | MSM261D4030H1CPM | C966942
USBC_INT | JP2 | Jumper_Trace_025x150x015
SW | TP2 | TestPoint_THTPad_1.0x1.0mm_Drill0.5mm
TP_INT | TP1 | TestPoint_THTPad_1.0x1.0mm_Drill0.5mm
I2C | J3 | JST_XH_B5B-XH-AM_1x05_P2.50mm_Vertical
GN 5V RGB GN | J9 | PinHeader_1x04_P2.54mm_Vertical
Fan2 | J11 | FanPinHeader_1x03_P2.54mm_Vertical
VPS | J12 | PinHeader_2x29_P2.54mm_Vertical
SPI-I2C | JP3 | SolderJumper-3_P1.3mm_Open_RoundedPad1.0x1.5mm_NumberLabels
SPI-I2C | JP4 | SolderJumper-3_P1.3mm_Open_RoundedPad1.0x1.5mm_NumberLabels
MOSI | JP6 | SolderJumper-2_P1.3mm_Open_RoundedPad1.0x1.5mm
CLK | JP7 | SolderJumper-2_P1.3mm_Open_RoundedPad1.0x1.5mm
10k | RV1 | Potentiometer_Alps_RK09K_Single_Vertical
Srvo | J2 | PinHeader_2x03_P2.54mm_Vertical
485 | J7 | WR_MJ_Modular_Jack_Vertical_Plastic_6P6C
SPK | J13 | SolderWire-0.1sqmm_1x02_P3.6mm_D0.4mm_OD1mm
1wire | J4 | JST_XH_B4B-XH-AM_1x04_P2.50mm_Vertical
FAN_6024 | X1 | FAN_6024
EXT | J5 | JST_XH_B6B-XH-AM_1x06_P2.50mm_Vertical
YELLOW | SW2 | RotaryEncoder_Alps_EC11E-Switch_Vertical_H20mm
Fan1 | J10 | FanPinHeader_1x03_P2.54mm_Vertical
IPS_240_240 | U14 | IPS_240_240_1.3
OFF TERM ON | SW6 | Switch_SS12D00
LED HTR | SW7 | Switch_SS12D00
REL ROT | SW8 | Switch_SS12D00
Fiducial | FID1 | Fiducial_1mm_Mask2mm
Fiducial | FID2 | Fiducial_1mm_Mask2mm
Speaker | IMG1 | speaker
PROG 5V POWER | SW11 | Switch_SS12D00
SNS MOV | SW9 | Switch_SS12D00
5V FAN 24V | SW10 | Switch_SS12D00
5V 3V GN 24 | J6 | JST_XH_B4B-XH-AM_1x04_P2.50mm_Vertical
Power | J18 | BarrelJack_Horizontal
HOT | IMG7 | hot
Augenschutz | IMG2 | googles
BME280 | J16 | PinSocket_1x06_P2.54mm_Vertical
CCS811 | J17 | PinSocket_1x08_P2.54mm_Vertical
DS18B20 | U7 | TO-92_HandSolder
BME680 | U12 | Bosch_LGA-8_3x3mm_P0.8mm_ClockwisePinNumbering
BME280 | U13 | Bosch_LGA-8_2.5x2.5mm_P0.65mm_ClockwisePinNumbering
CCS811 | U15 | AMS_LGA-10-1EP_2.7x4mm_P0.6mm
BH1750 | U20 | GY-302
AM612 | U22 | AM612
Augenschutz | IMG9 | qwiic
Speaker | SP1 | SPEAKER_2415
XGZP6897D | X2 | XGZP6897D
AudioJack3_SwitchT | J22 | PJ-327A
47u | C45 | CP_Elec_5x5.4
24 GN GN OUT | J24 | JST_XH_S4B-XH-A_1x04_P2.50mm_Horizontal
47u | C43 | C_0603_1608Metric
MPU-6050 | U23 | InvenSense_QFN-24_4x4mm_P0.5mm
47u | C13 | C_0603_1608Metric
AUDIO | JP1 | SolderJumper-3_P1.3mm_Open_RoundedPad1.0x1.5mm_NumberLabels
47u | C46 | CP_Elec_5x5.4
TIP41 | Q7 | TO-220-3_Horizontal_TabUp
1B 2A | J15 | PhoenixContact_MCV_1,5_2-G-3.81_1x02_P3.81mm_Vertical
UDA1334 | U5 | SSOP-16_4.4x5.2mm_P0.65mm
22R | R18 | Resistor_100W
QR-CODE | IMG5 | QR_CODE_smopla_de
OPEN Hardware | IMG6 | OSHW-Logo2_7.3x6mm_SilkScreen
HOT_BIG | IMG8 | hot_big
FHOS | IMG4 | LOGO_FHOS_80mm
FAN5V | J20 | JST_XH_B2B-XH-A_1x02_P2.50mm_Vertical
DS18B20 | U19 | TO-92_HandSolder
GL5516 | R9 | R_LDR_5.1x4.3mm_P3.4mm_Vertical
1u | C21 | C_0805_2012Metric_Pad1.18x1.45mm_HandSolder
SPK | J19 | SolderWire-0.1sqmm_1x02_P3.6mm_D0.4mm_OD1mm
100u | C34 | C_1206_3216Metric_Pad1.33x1.80mm_HandSolder
NS4168 | U25 | SOIC-8_3.9x4.9mm_Pitch1.27mm_pad_handsolder
1 | NT2 | NetTie-2_SMD_Pad0.5mm
1 | NT1 | NetTie-2_SMD_Pad0.5mm
5V AMP 3V | JP5 | SolderJumper-3_P1.3mm_Open_RoundedPad1.0x1.5mm_NumberLabels
Ebyte E32 | X3 | Ebyte-E32-900T20D
SIM7080G | X4 | SIM7080G_AND_MODULE
NRF24L01 | U8 | nRF24L01_Breakout
Fan2toFan1 | JP8 | SolderJumper-2_P1.3mm_Open_RoundedPad1.0x1.5mm

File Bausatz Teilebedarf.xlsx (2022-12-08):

Typ | Kosten | Verfügbar | Benötigt | Bestellt | Bestellung bezahlt | 11.04.2022 | Kosten2 | Losgröße | 30
Hauptplatine bestückt | 19.31 € |  | 30
Lüfter 6015 | 1.47 € | 11 | 19 | 20 | ok | 16
Widerstand 100W, 22R | 1.42 € | 13 | 17 | 20 | ok | 16
PIR-Sensor BM612 | 0.98 € | 19 | 11 | 20 | ok | 16
Frontplatte gefräst gedruckt | 0.92 € |  | 30
Winkel 10mm | 0.60 € | 100 | -40 |  |  | 16
Spacer 50mm | 0.29 € |  | 120 | 150 | ok | 16
Lautsprecher 2415 | 0.28 € | 34 | -4 |  |  | 16
Drehencoder EC11 | 0.27 € | 18 | 12 | 50 | ok | 16
Temperatursensor DS18B20 | 0.27 € | 10 | 20 | 50 | ok | 16
RJ11 Buchse | 0.24 € | 40 | -10 |  |  | 16
Pfostenleiste 2reihigl 90° | 0.17 € | 30 | 0 |  |  | 16
TIP31C | 0.15 € | 29 | 1 | 50 | ok mit alter ID | 16
RV09 10k | 0.15 € | 50 | -20 |  |  | 16
Schiebeschalter SS12D00 | 0.14 € | 180 | 0 |  |  | 12
Muttern M3 | 0.11 € | 100 | 80 |  |  | 16
Fresnel-Linse | 0.08 € | 19 | 11 | 20 | ok | 16
Spacer 10mm | 0.08 € |  | 120 | 150 | ok | 16
Schrauben M3x20 | 0.07 € | 100 | -40 |  |  | 16
Spacer 6mm | 0.06 € |  | 120 | 150 | ok | 16
Wärmeleitpaste | 0.06 € |  | 30
Schrauben M3x6 | 0.05 € | 100 | -40 |  |  | 16
GL5516 | 0.05 € | 15 | 15 | 100 | ok | 16
Buchsenleiste 8pol | 0.05 € |  | 30 | 100 | ok | 16
Buchsenleiste 6pol | 0.04 € | 20 | 10 | 100 | ok | 16
Lüferanschlüuss 3pol KF2510 | 0.04 € | 44 | -14 |  |  | 16
Buchsenleiste 5pol | 0.04 € |  | 30 | 100 | ok | 16
JST 4pol 90° | 0.03 € | 45 | -15 |  |  | 16
JST 4pol gerade | 0.03 € | 45 | -15 |  |  | 16
Isolatorplättchen | 0.01 € | 100 | -40 |  |  | 16
Isolatorscheiben | 0.01 € | 100 | -40 |  |  | 16
JST 2pol gerade | 0.01 € | 32 | -2 |  |  | 16
Tastenkappe Rot | 0.01 € | 100 | -70 |  |  | 16
Tastenkappe Grün | 0.01 € | 100 | -70 |  |  | 16
Drehkappe gelb | 0.01 € | 40 | -10 |  |  | 16
Tastenkappe blau | 0.01 € | 100 | -70 |  |  | 16
Tastenkappe weiß | 0.01 € | 100 | -70 |  |  | 16

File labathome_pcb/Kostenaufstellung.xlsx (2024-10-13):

Teil | Einzelpreis bei 50er-Menge
PCB | 23.62
Encoder | 0.3
Display | 1.8
Speaker | 0.4
DS18B20 | 0.8
Schiebeschalter | 0.1
Elko | 0.1
Widerstand | 0.1
LDR | 0.1
PIR | 1

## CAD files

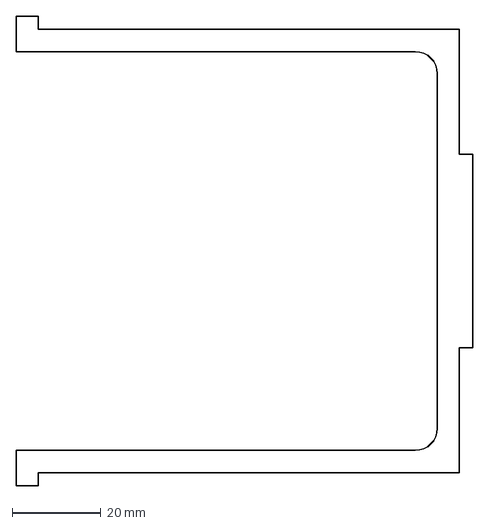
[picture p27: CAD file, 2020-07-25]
enclosure/Platinenhalterung hinten.dxf
103.0 x 106.0 mm

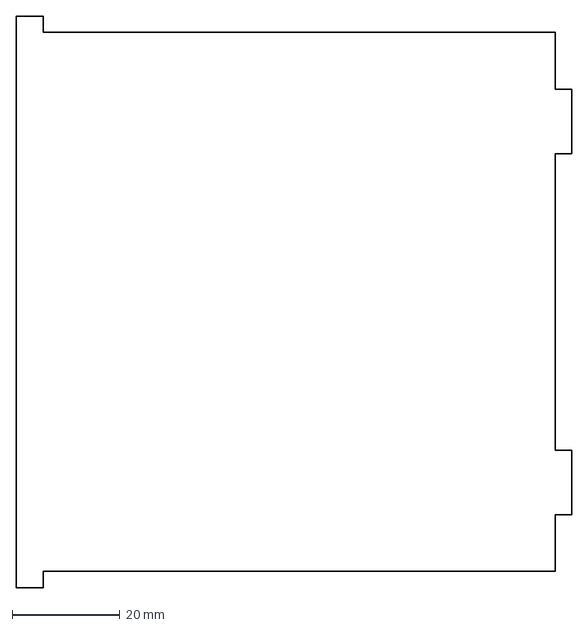
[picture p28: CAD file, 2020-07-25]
enclosure/Trennwand 2.dxf
103.0 x 106.0 mm

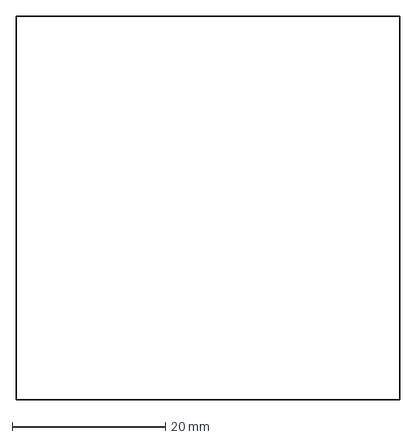
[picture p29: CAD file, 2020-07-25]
enclosure/Klappe 2.dxf
50.0 x 50.0 mm

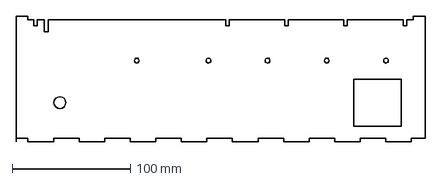
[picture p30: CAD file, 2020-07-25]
enclosure/Seitenwand 2.dxf
345.6 x 106.0 mm

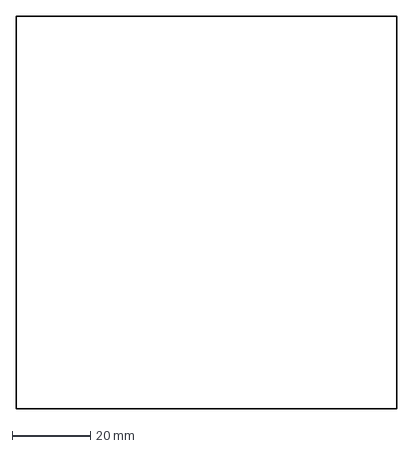
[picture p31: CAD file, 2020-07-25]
enclosure/Befestigungsplatte Axialventilator Klappenmotor.dxf
97.0 x 100.0 mm

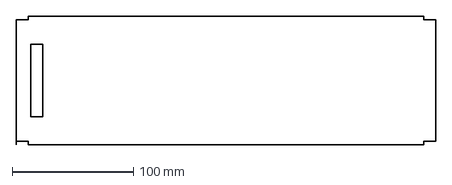
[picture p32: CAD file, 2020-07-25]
enclosure/Deckel.dxf
345.6 x 106.0 mm

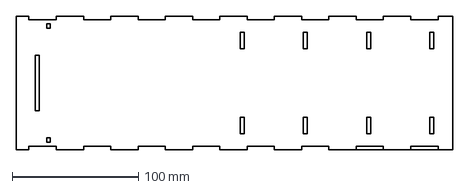
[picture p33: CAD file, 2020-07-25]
enclosure/Boden.dxf
345.6 x 106.0 mm

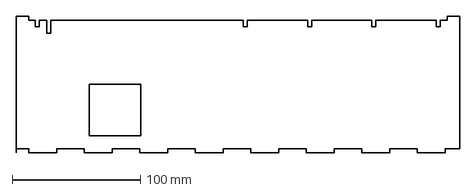
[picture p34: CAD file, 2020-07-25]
enclosure/Seitenwand 1.dxf
345.6 x 106.0 mm

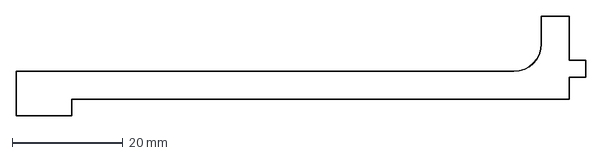
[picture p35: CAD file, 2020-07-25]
enclosure/Platinenhalterung vorne 1.dxf
103.0 x 18.0 mm

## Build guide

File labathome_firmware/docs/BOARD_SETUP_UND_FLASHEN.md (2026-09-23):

# Board-Inbetriebnahme und Flashen

Kurzreferenz für den C#-Build-Orchestrator (`builder/`), der `idf.py`/`esptool` steuert und dabei
Board-Identität, Zertifikate, Sprachausgaben, Web-App und Firmware generiert. Hintergrund zur
Umstellung von Gulp auf diesen Builder: [MIGRATION_TO_BESTBINARYBUFFERS.md](MIGRATION_TO_BESTBINARYBUFFERS.md).

Alle Befehle unten werden im Verzeichnis `labathome_firmware/` ausgeführt (PowerShell oder
ESP-IDF-Konsole).

## Voraussetzungen (einmalig pro Rechner)

- .NET SDK 10 installiert (`dotnet --version`)
- ESP-IDF installiert; `IDF_PATH` zeigt auf das ESP-IDF-Installationsverzeichnis (das Verzeichnis,
  das `export.bat` enthält)
- **Die Konsole, in der `dotnet run` gestartet wird, muss eine bereits aktivierte
  ESP-IDF-Umgebung sein** (z.B. die vom ESP-IDF-Installer angelegte Verknüpfung
  "ESP-IDF X.Y PowerShell/CMD", oder manuell vorher `& "$Env:IDF_PATH\export.ps1"` aufrufen).
  Grund: `PrepareContextWithRealHardware` und `FlashFirmware` rufen `esptool`/`espefuse` direkt
  auf (ohne selbst `export.bat` dazwischenzuschalten) und brauchen sie daher schon auf `PATH`. Der
  Schritt `BuildFirmware` aktiviert die Umgebung zwar zusätzlich selbst noch einmal für seinen
  `idf.py`-Aufruf, das ersetzt aber nicht die aktivierte Konsole für die anderen Schritte.
- `builder/appsettings.json` existiert und ist korrekt ausgefüllt. Sie wird beim ersten
  `dotnet build`/`dotnet run` automatisch aus `builder/appsettings.json.template` angelegt
  (gitignored, weil rechnerspezifisch) und muss dann einmalig angepasst werden:
  - `BoardStorage:BoardsDir` -- Archiv-Verzeichnis, in dem pro Board (nach MAC) Zertifikate,
    Sprachausgabe und `board_info.json` abgelegt werden
  - `Certificates:CertsDir` -- Ablage für die selbstsignierte Root-CA (wird beim ersten Board
    automatisch erzeugt, danach wiederverwendet)
  - `NpmPackagesDir`, `WebmanagerBestBinaryBuffersSchemaDir` -- Pfade zu den Nachbar-Repos
    (s. Haupt-README, Abschnitt "Checke diverse Repositories aus")
  - `GoogleTtsCredentialsFile` -- optional; ohne gültige Google-TTS-Zugangsdaten wird für die
    Begrüßungsansage "ready.mp3" automatisch ein Platzhalter (`ok.mp3`) verwendet
- Board per USB angeschlossen, bevor ein Schritt mit Hardwarezugriff aufgerufen wird

## Neues Board in Betrieb nehmen

Ein "neues" Board ist eines, dessen MAC-Adresse noch nicht im Board-Archiv (`BoardsDir`) bekannt
ist. Einmaliger Komplettlauf über alle Schritte (Hardware erkennen und Board-Archiv anlegen,
Protokoll-/Runtime-Konfiguration generieren, Zertifikat erzeugen, Sprachausgabe erzeugen, Web-App
bauen, Firmware bauen, Firmware flashen):

```powershell
dotnet run --project builder -- Pipeline
```

Für die ältere Platinen-Revision mit klassischem ESP32 (Rev. 5.x) muss die Board-Version explizit
mitgegeben werden, da sonst der Default (Rev. 15.3, ESP32-S3) angenommen wird:

```powershell
dotnet run --project builder -- Pipeline --boardVersion 5.1
```

`--boardVersion` akzeptiert `5.1`, `5.1.0` oder die sechsstellig gepolsterte Zahl `050100`. Die
erste Ziffer wählt HAL-Verzeichnis (`main/hal/05` bzw. `main/hal/15`) und ESP-IDF-Target
(`esp32` bzw. `esp32s3`) -- Details dazu in [LabathomeBuildContext.cs](../builder/LabathomeBuildContext.cs).

Nach erfolgreichem Lauf zeigt die Konsole Board-Version, HAL-Verzeichnis, IDF-Target und
Board-Verzeichnis an. Sobald die Firmware startet, meldet sich das Board per Sprachausgabe
(inkl. Hostname) und ist über den angezeigten Hostnamen im Netz erreichbar.

## Bereits bekanntes Board (erneut) flashen

Board per USB anschließen (dieselbe Platine wie beim ersten Mal, also dieselbe MAC) und denselben
Befehl wie oben erneut aufrufen:

```powershell
dotnet run --project builder -- Pipeline
```

`PrepareContextWithRealHardware` erkennt das Board an seiner MAC im Archiv, aktualisiert nur den
Zeitstempel "zuletzt verbunden" und übernimmt automatisch die zuvor gespeicherte Board-Version --
`--boardVersion` wird für ein bereits bekanntes Board ignoriert (wirkt nur beim Neuanlegen).

### Nur neu flashen, ohne alles neu zu generieren

Wenn Zertifikat/Sounds/Web-App/Runtime-Config schon aktuell sind und sich nur der C++-Code
geändert hat, reicht:

```powershell
dotnet run --project builder -- BuildFirmware
dotnet run --project builder -- FlashFirmware
```

Diese beiden Schritte arbeiten mit dem zuletzt verwendeten Board aus dem `board_info.json` im
Repo-Root (angelegt/aktualisiert von `PrepareContextWithRealHardware`) -- ohne erneuten
Hardwarezugriff für `BuildFirmware`, aber `FlashFirmware` braucht das Board angeschlossen.

Optional kann beim Flashen die NVS-Partition (WLAN-/Usersettings) mitgelöscht werden:

```powershell
dotnet run --project builder -- FlashFirmware --resetNVSPartition
```

### Nur bauen, ohne Board (z.B. CI, oder Board gerade nicht angeschlossen)

```powershell
dotnet run --project builder -- PipelineBuildOnly
```

Baut für das zuletzt verwendete Board (aus `board_info.json`), ohne Hardwarezugriff und ohne zu
flashen.

## Weitere nützliche Einzelschritte

Alle Schritte lassen sich auch einzeln aufrufen (`dotnet run --project builder -- <Schritt>
[Argumente]`), z.B. zum gezielten Nacharbeiten:

| Schritt | Zweck |
| --- | --- |
| `Info` | Zeigt Board-Version, HAL-Verzeichnis, IDF-Target und (falls Board angeschlossen) ob die MAC des Live-Boards zum Archiv-Eintrag passt |
| `GitStatus` | Zeigt aktuellen Git-Branch/Commit/Dirty-Status |
| `SetBoardVersion --boardVersion <5.1\|15.3\|...>` | Ändert nachträglich die Hardware-Revision des zuletzt verwendeten Boards, ohne Hardwarezugriff |
| `GenerateBestBinaryBufferFiles` | Generiert C++/TypeScript aus den BestBinaryBuffers-Schemas |
| `GenerateRuntimeConfig` | Generiert Runtime-Defines (Hostname, Board-Infos, Zugangsdaten, ...) für C++, CMake und TypeScript |
| `GenerateCertificates` | Erzeugt (lazy) Root-CA und Board-Zertifikat |
| `GenerateSounds` | Erzeugt (lazy, per Google TTS) Sprachausgaben, inkl. Board-spezifischer Begrüßung |
| `BuildWebApp` | Baut die Web-Oberfläche |
| `BuildFirmware` | Ruft `idf.py build` für das aktuelle Board (Target/HAL/sdkconfig passend) auf |
| `FlashFirmware [--resetNVSPartition]` | Flasht die zuletzt gebaute Firmware per `esptool` |

**Hinweis Flash-Verschlüsselung:** Ist im Board-Archiv `flashEncryptionKeyBurnedAndActivated:
true` vermerkt, bricht `FlashFirmware` bewusst mit einer `NotImplementedException` ab -- der
verschlüsselte Flash-Pfad ist (noch) nicht implementiert.

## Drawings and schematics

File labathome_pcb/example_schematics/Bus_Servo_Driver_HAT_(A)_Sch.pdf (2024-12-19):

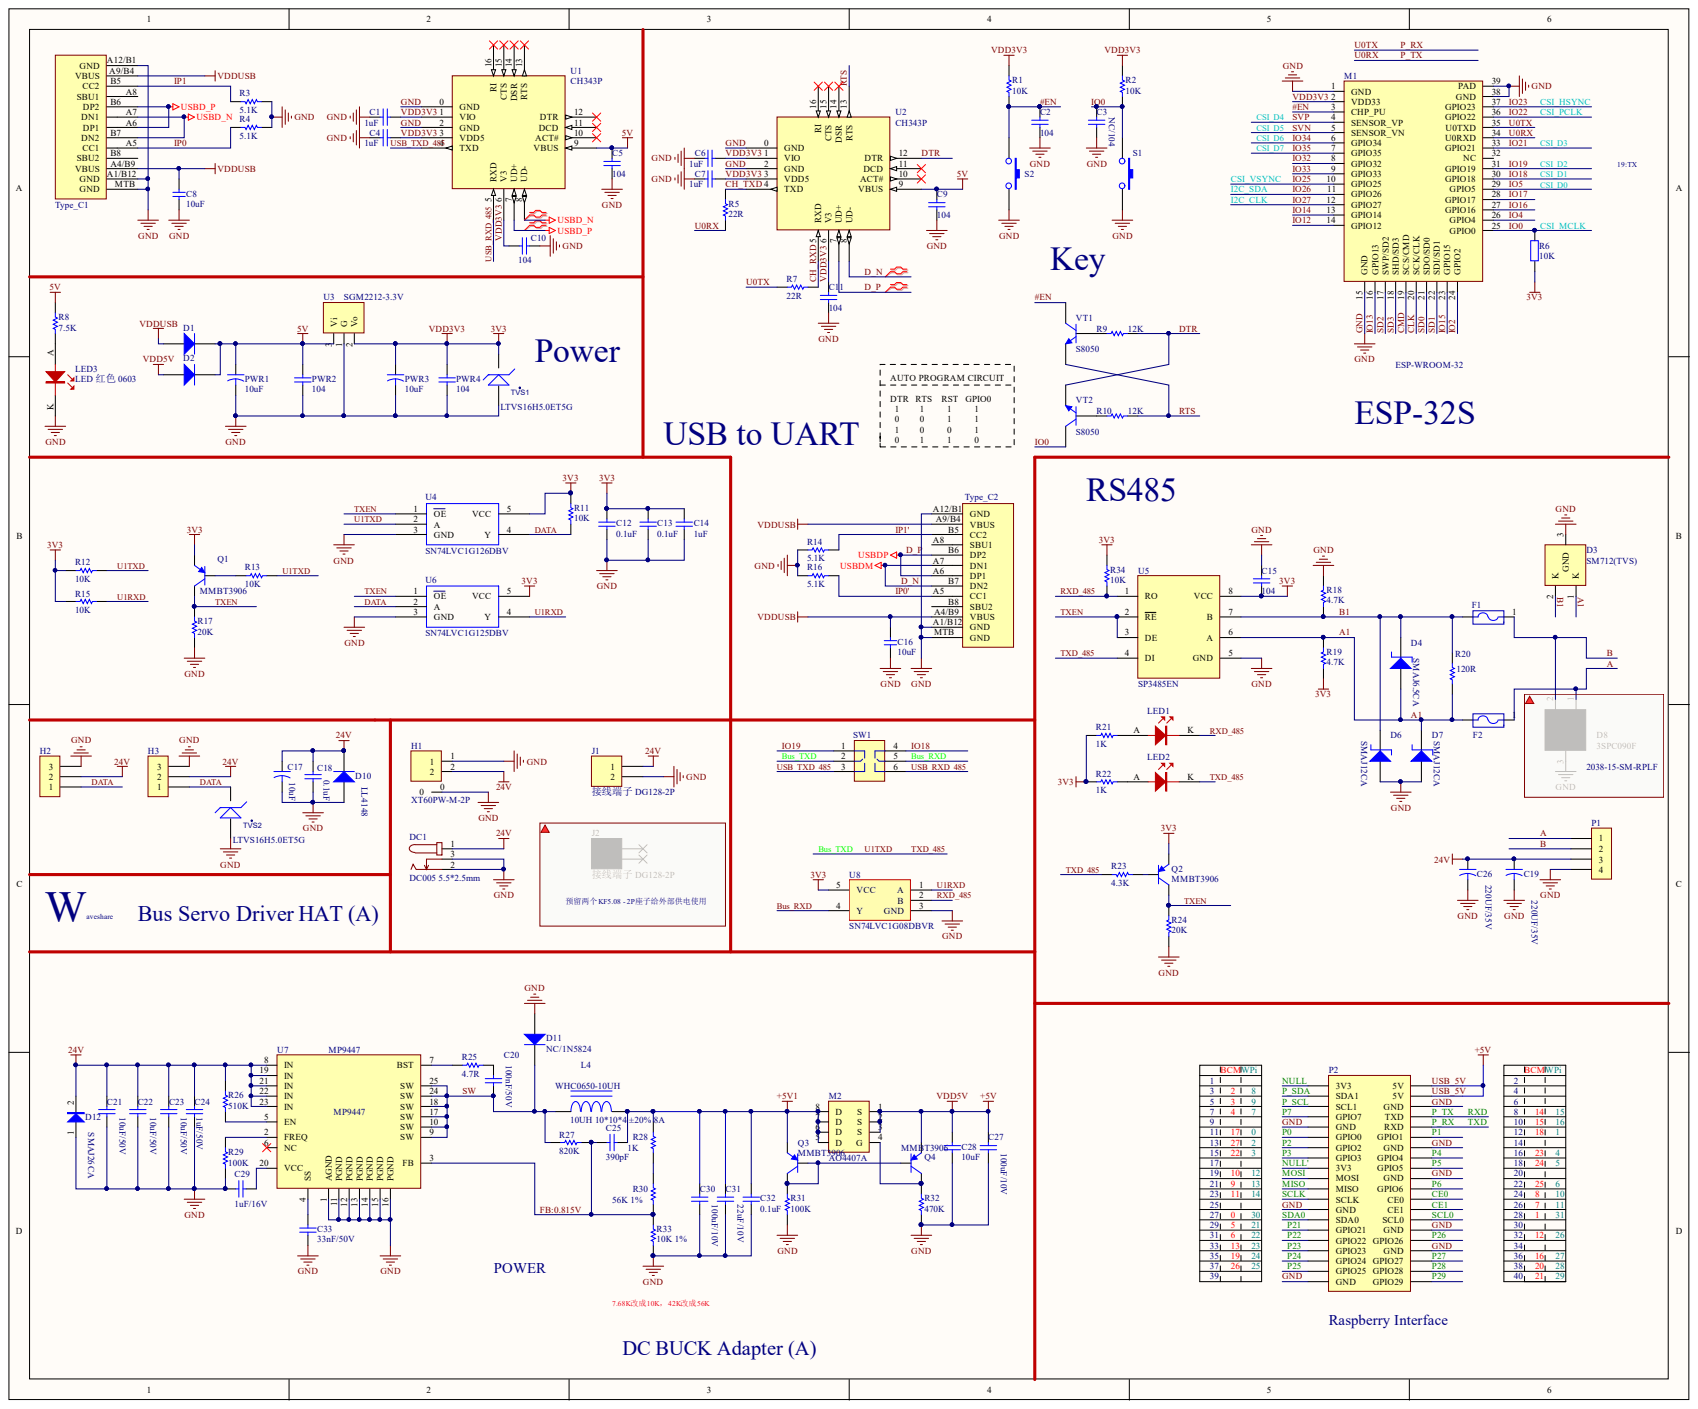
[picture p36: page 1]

ESP-32S USB to UART

SBU1 A8

Bus Servo Driver HAT (A)

21 | 9 | 13 | MISO | P6 | 22 | 25 | 6
23 | 11 | 14 | SCLK | CE0 | 24 | 8 | 10
25 | | | GND | CE1 | 26 | 7 | 11

31 | 6 | 22 | P22 | P26 | 32 | 12 | 26
33 | 13 | 23 | P23 | GND | 34

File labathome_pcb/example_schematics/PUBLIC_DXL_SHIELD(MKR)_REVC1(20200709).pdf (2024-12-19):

# J1 PinSocket_2.54_1x14

AREF 1 A0(DAC0) 2 A1 3 A2 4 A3 5 A4 6 A5 7 A6 8 D0(W0) 9 D1(W1) 10 D2(W2) 11 D3(W3) 12 D4(W4) 13 D5(W5) 14

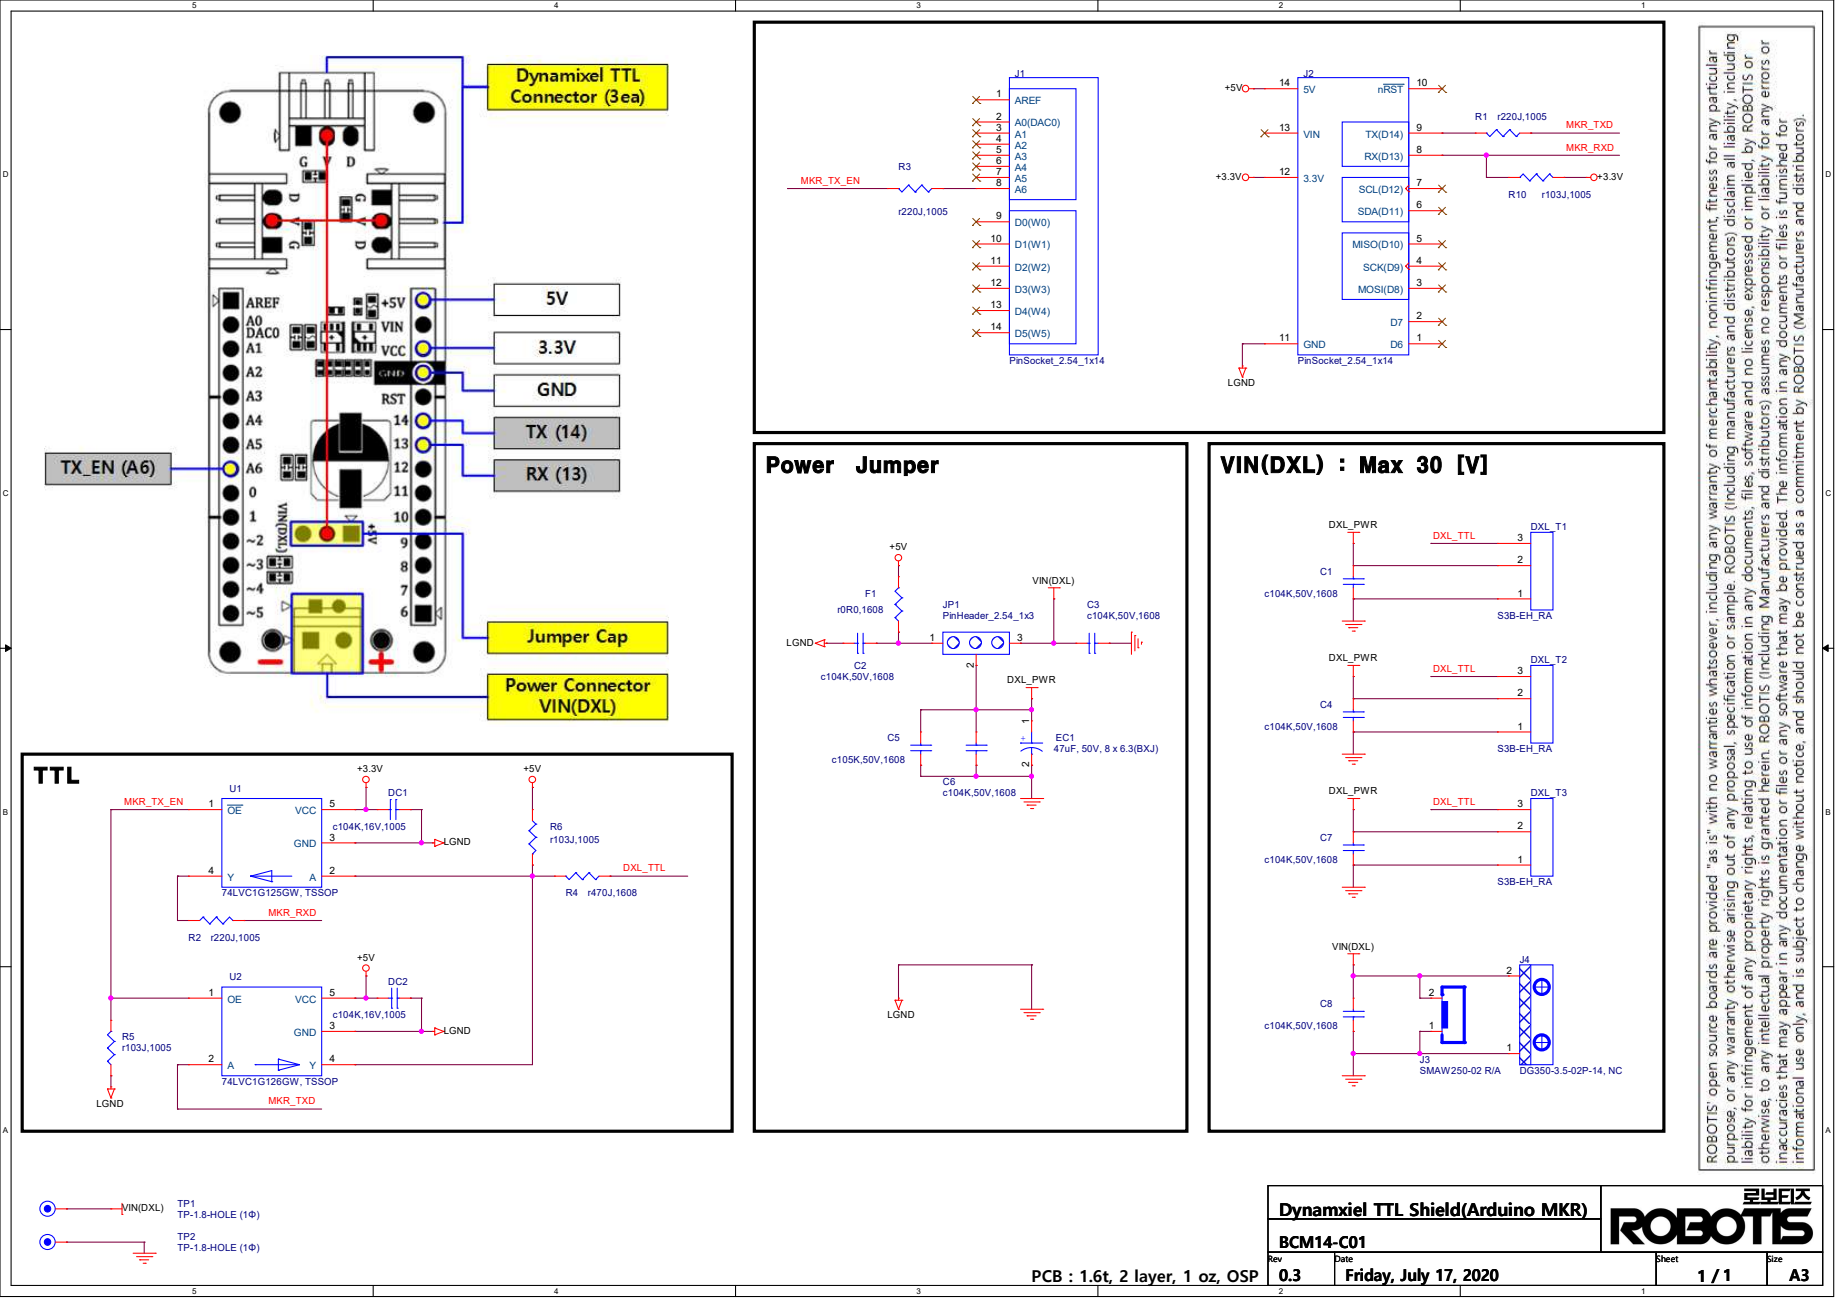
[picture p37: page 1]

nRST 10 TX(D14) 9 RX(D13) 8 SCL(D12) 7 SDA(D11) 6 MISO(D10) 5 SCK(D9) 4 MOSI(D8) 3 D7 2 D6 1 C4

Dynamxiel TTL Shield(Arduino MKR)
Date BCM14-C01

PCB : 1.6t, 2 layer, 1 oz, OSP

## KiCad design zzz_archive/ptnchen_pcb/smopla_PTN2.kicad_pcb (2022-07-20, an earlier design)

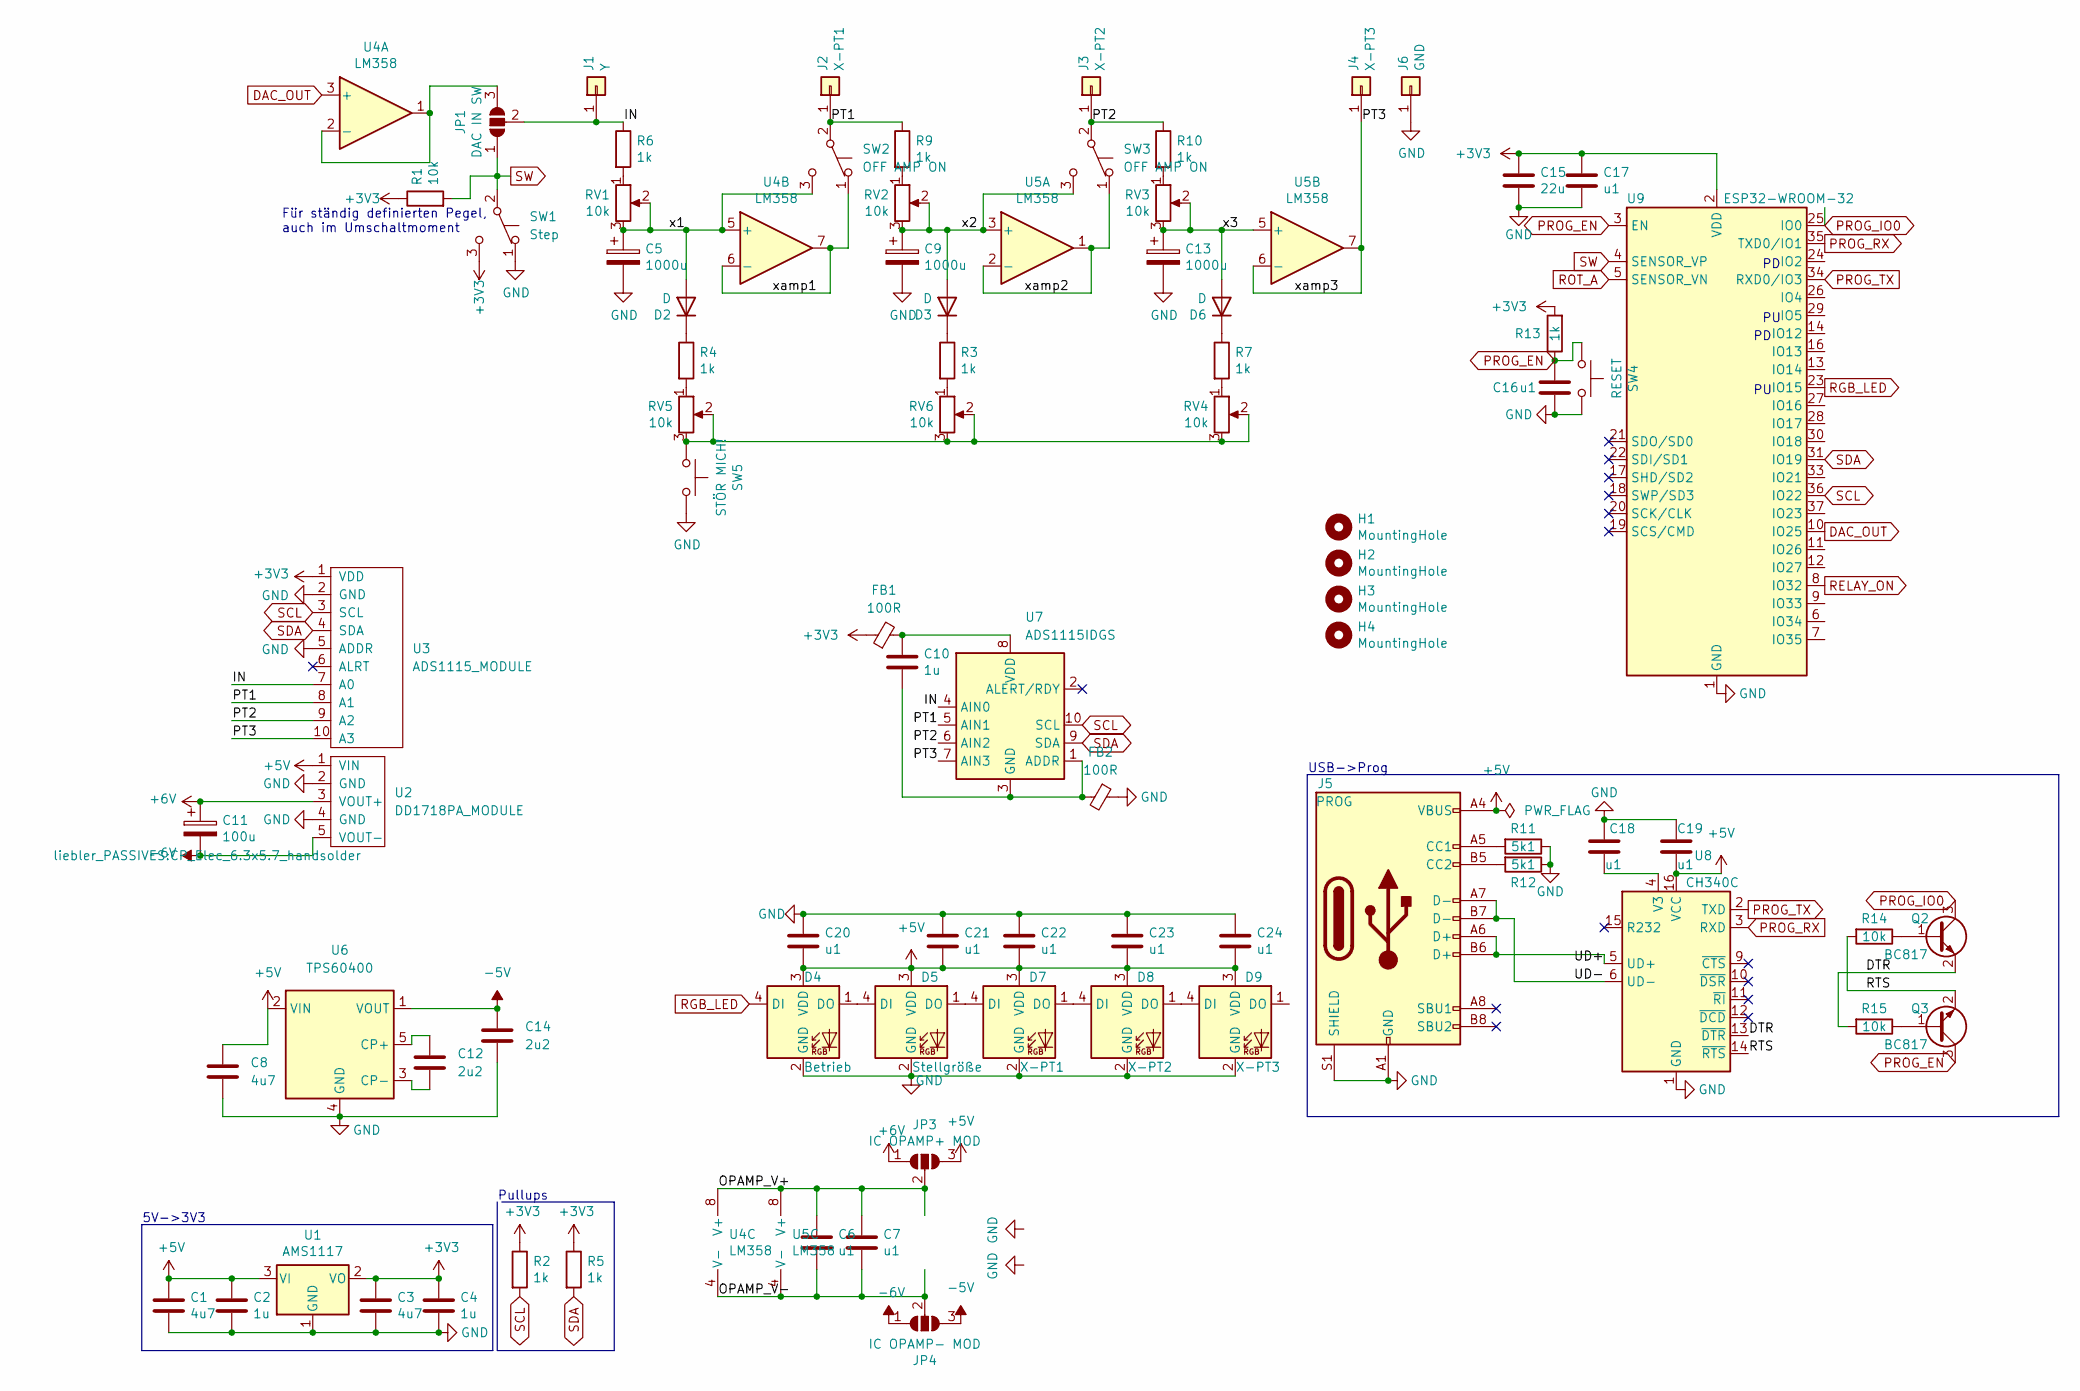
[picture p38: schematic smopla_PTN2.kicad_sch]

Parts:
C1, C3, C8: 4u7; C_0805_2012Metric_Pad1.18x1.45mm_HandSolder
C2, C4, C10: 1u; C_0805_2012Metric_Pad1.18x1.45mm_HandSolder
C5, C9, C13: 1000u; CP_Elec_10x10_handsolder; JLCPCB C280409
C6, C7, C16, C17, C18, C19, C20, C21, C22, C23, C24: u1; C_0805_2012Metric_Pad1.18x1.45mm_HandSolder
C11: 100u; CP_Elec_6.3x5.7_handsolder
C12, C14: 2u2; C_0805_2012Metric_Pad1.18x1.45mm_HandSolder
C15: 22u; C_0805_2012Metric_Pad1.18x1.45mm_HandSolder
D2, D3, D6: D; D_SOD-123_handsolder
D4: Betrieb; LED_D5.0mm-4_RGB_Staggered_Pins
D5: Stellgröße; LED_D5.0mm-4_RGB_Staggered_Pins
D7: X-PT1; LED_D5.0mm-4_RGB_Staggered_Pins
D8: X-PT2; LED_D5.0mm-4_RGB_Staggered_Pins
D9: X-PT3; LED_D5.0mm-4_RGB_Staggered_Pins
FB1, FB2: 100R; L_0805_2012Metric_Pad1.05x1.20mm_HandSolder
H1, H2, H3, H4: MountingHole; MountingHole_3.2mm_M3_DIN965
J1: Y; Banana_RECESSED
J2: X-PT1; Banana_RECESSED
J3: X-PT2; Banana_RECESSED
J4: X-PT3; Banana_RECESSED
J5: PROG; USB_C_Receptacle_HRO_TYPE-C-31-M-12_IMPROVED
J6: GND; Banana_RECESSED
JP1: DAC IN SW; SolderJumper-3_P1.3mm_Open_RoundedPad1.0x1.5mm_NumberLabels
JP3: IC OPAMP+ MOD; SolderJumper-3_P1.3mm_Open_RoundedPad1.0x1.5mm_NumberLabels
JP4: IC OPAMP- MOD; SolderJumper-3_P1.3mm_Open_RoundedPad1.0x1.5mm_NumberLabels
Q2, Q3: BC817; SOT-23_Handsoldering
R1, R14, R15: 10k; R_0805_2012Metric_Pad1.20x1.40mm_HandSolder
R2, R3, R4, R5, R6, R7, R9, R10, R13: 1k; R_0805_2012Metric_Pad1.20x1.40mm_HandSolder
R11, R12: 5k1; R_0805_2012Metric_Pad1.20x1.40mm_HandSolder
RV1, RV2, RV3: 10k; Potentiometer_Alps_RK09K_Single_Vertical
RV4, RV5, RV6: 10k; Potentiometer_Bourns_3386P_Vertical
SW1: Step; MTS-102_recessed
SW2, SW3: OFF AMP ON; Switch_SS12D00
SW4: RESET; SW_SPST_TL3342
SW5: STÖR MICH!; Button_12mm_ANCHOR_CENTER
U1: AMS1117; SOT-223-3_TabPin2_HANDSOLDER
U2: DD1718PA_MODULE; DD1718PA_MODULE_SMD
U3: ADS1115_MODULE; ADS1115_MODULE_SMD
U4, U5: LM358; SOIC-8_3.9x4.9mm_Pitch1.27mm_handsolder
U6: TPS60400; SOT-23-5
U7: ADS1115IDGS; TSSOP-10_3x3mm_P0.5mm
U8: CH340C; SOIC-16_3.9x9.9mm_P1.27mm
U9: ESP32-WROOM-32

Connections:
+3V3: C3.2, C4.1, C15.1, C17.2, FB1.1, R1.1, R2.1, R5.1, R13.2, SW1.3 (C), U1.2 (VO), U3.1 (VDD), U9.2 (VDD)
+5V: C1.2, C2.1, C8.1, C19.1, C20.2, C21.2, C22.2, C23.2, C24.2, D4.3 (VDD), D5.3 (VDD), D7.3 (VDD), D8.3 (VDD), D9.3 (VDD), J5.A4 (VBUS), J5.A9 (VBUS), J5.B4 (VBUS), J5.B9 (VBUS), JP3.3 (B), U1.3 (VI), U2.1 (VIN), U6.2 (VIN), U8.16 (VCC)
+6V: C11.1, JP3.1 (A), U2.3 (VOUT+)
-5V: C14.1, JP4.3 (B), U6.1 (VOUT)
-6V: C11.2, JP4.1 (A), U2.5 (VOUT-)
/DTR: Q2.2 (E), R15.2, U8.13 (~DTR)
/IN: J1.1, JP1.2 (C), R6.1, U3.7 (A0), U7.4 (AIN0)
/OPAMP_V+: C6.1, C7.1, JP3.2 (C), U4.8 (V+), U5.8 (V+)
/OPAMP_V-: C6.2, C7.2, JP4.2 (C), U4.4 (V-), U5.4 (V-)
/PT1: J2.1, R9.1, SW2.2 (B), U3.8 (A1), U7.5 (AIN1)
/PT2: J3.1, R10.1, SW3.2 (B), U3.9 (A2), U7.6 (AIN2)
/PT3: J4.1, U3.10 (A3), U5.6 (-), U5.7, U7.7 (AIN3)
/RTS: Q3.2 (E), R14.2, U8.14 (~RTS)
/UD+: J5.A6 (D+), J5.B6 (D+), U8.5 (UD+)
/UD-: J5.A7 (D-), J5.B7 (D-), U8.6 (UD-)
/x1: C5.1, D2.2 (A), RV1.2, RV1.3, SW2.3 (C), U4.5 (+)
/x2: C9.1, D3.2 (A), RV2.2, RV2.3, SW3.3 (C), U5.3 (+)
/x3: C13.1, D6.2 (A), RV3.2, RV3.3, U5.5 (+)
/xamp1: SW2.1 (A), U4.6 (-), U4.7
/xamp2: SW3.1 (A), U5.1, U5.2 (-)
DAC_OUT: U4.3 (+), U9.10 (IO25)
GND: C1.1, C2.2, C3.1, C4.2, C5.2, C8.2, C9.2, C13.2, C14.2, C15.2, C16.1, C17.1, C18.2, C19.2, C20.1, C21.1, C22.1, C23.1, C24.1, D4.2 (GND), D5.2 (GND), D7.2 (GND), D8.2 (GND), D9.2 (GND), FB2.1, J5.A1 (GND), J5.A12 (GND), J5.B1 (GND), J5.B12 (GND), J5.S1 (SHIELD), J6.1, R11.1, R12.1, SW1.1 (A), SW4.2, SW5.2, U1.1 (GND), U2.2 (GND), U2.4 (GND), U3.2 (GND), U3.5 (ADDR), U6.4 (GND), U8.1 (GND), U9.1 (GND), U9.15 (GND), U9.38 (GND), U9.39 (GND)
unnamed: C10.1, FB2.2, U7.1 (ADDR), U7.3 (GND)
unnamed: C10.2, FB1.2, U7.8 (VDD)
unnamed: C12.1, U6.5 (CP+)
unnamed: C12.2, U6.3 (CP-)
unnamed: C18.1, U8.4 (V3)
unnamed: D2.1 (K), R4.1
unnamed: D3.1 (K), R3.1
unnamed: D4.1 (DO), D5.4 (DI)
unnamed: D5.1 (DO), D7.4 (DI)
unnamed: D6.1 (K), R7.1
unnamed: D7.1 (DO), D8.4 (DI)
unnamed: D8.1 (DO), D9.4 (DI)
unnamed: J5.A5 (CC1), R11.2
unnamed: J5.B5 (CC2), R12.2
unnamed: JP1.3 (B), U4.1, U4.2 (-)
unnamed: Q2.1 (B), R14.1
unnamed: Q3.1 (B), R15.1
unnamed: R3.2, RV6.1
unnamed: R4.2, RV5.1
unnamed: R6.2, RV1.1
unnamed: R7.2, RV4.1
unnamed: R9.2, RV2.1
unnamed: R10.2, RV3.1
unnamed: RV4.2, RV4.3, RV5.2, RV5.3, RV6.2, RV6.3, SW5.1
PROG_EN: C16.2, Q3.3 (C), R13.1, SW4.1, U9.3 (EN)
PROG_IO0: Q2.3 (C), U9.25 (IO0)
PROG_RX: U8.3 (RXD), U9.35 (TXD0/IO1)
PROG_TX: U8.2 (TXD), U9.34 (RXD0/IO3)
RELAY_ON: U9.8 (IO32)
RGB_LED: D4.4 (DI), U9.23 (IO15)
ROT_A: U9.5 (SENSOR_VN)
SCL: R2.2, U3.3 (SCL), U7.10 (SCL), U9.36 (IO22)
SDA: R5.2, U3.4 (SDA), U7.9 (SDA), U9.31 (IO19)
SW: JP1.1 (A), R1.2, SW1.2 (B), U9.4 (SENSOR_VP)

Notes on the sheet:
USB->Prog
Für ständig definierten Pegel, auch im Umschaltmoment
5V->3V3
Pullups

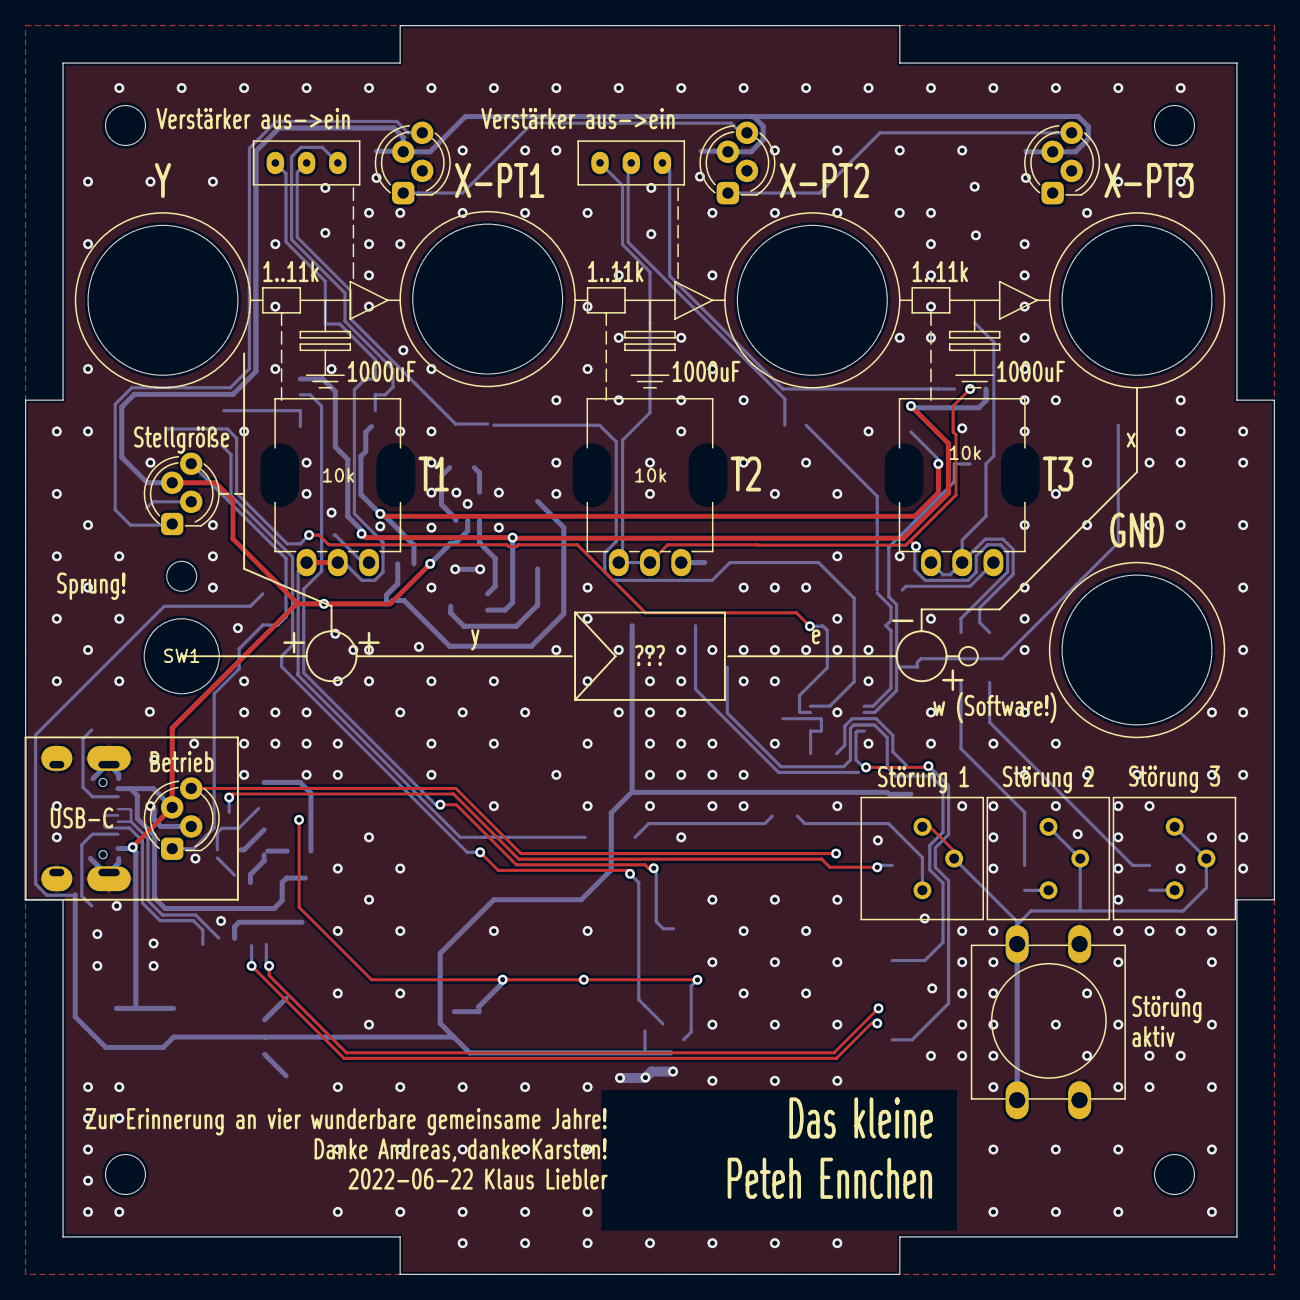
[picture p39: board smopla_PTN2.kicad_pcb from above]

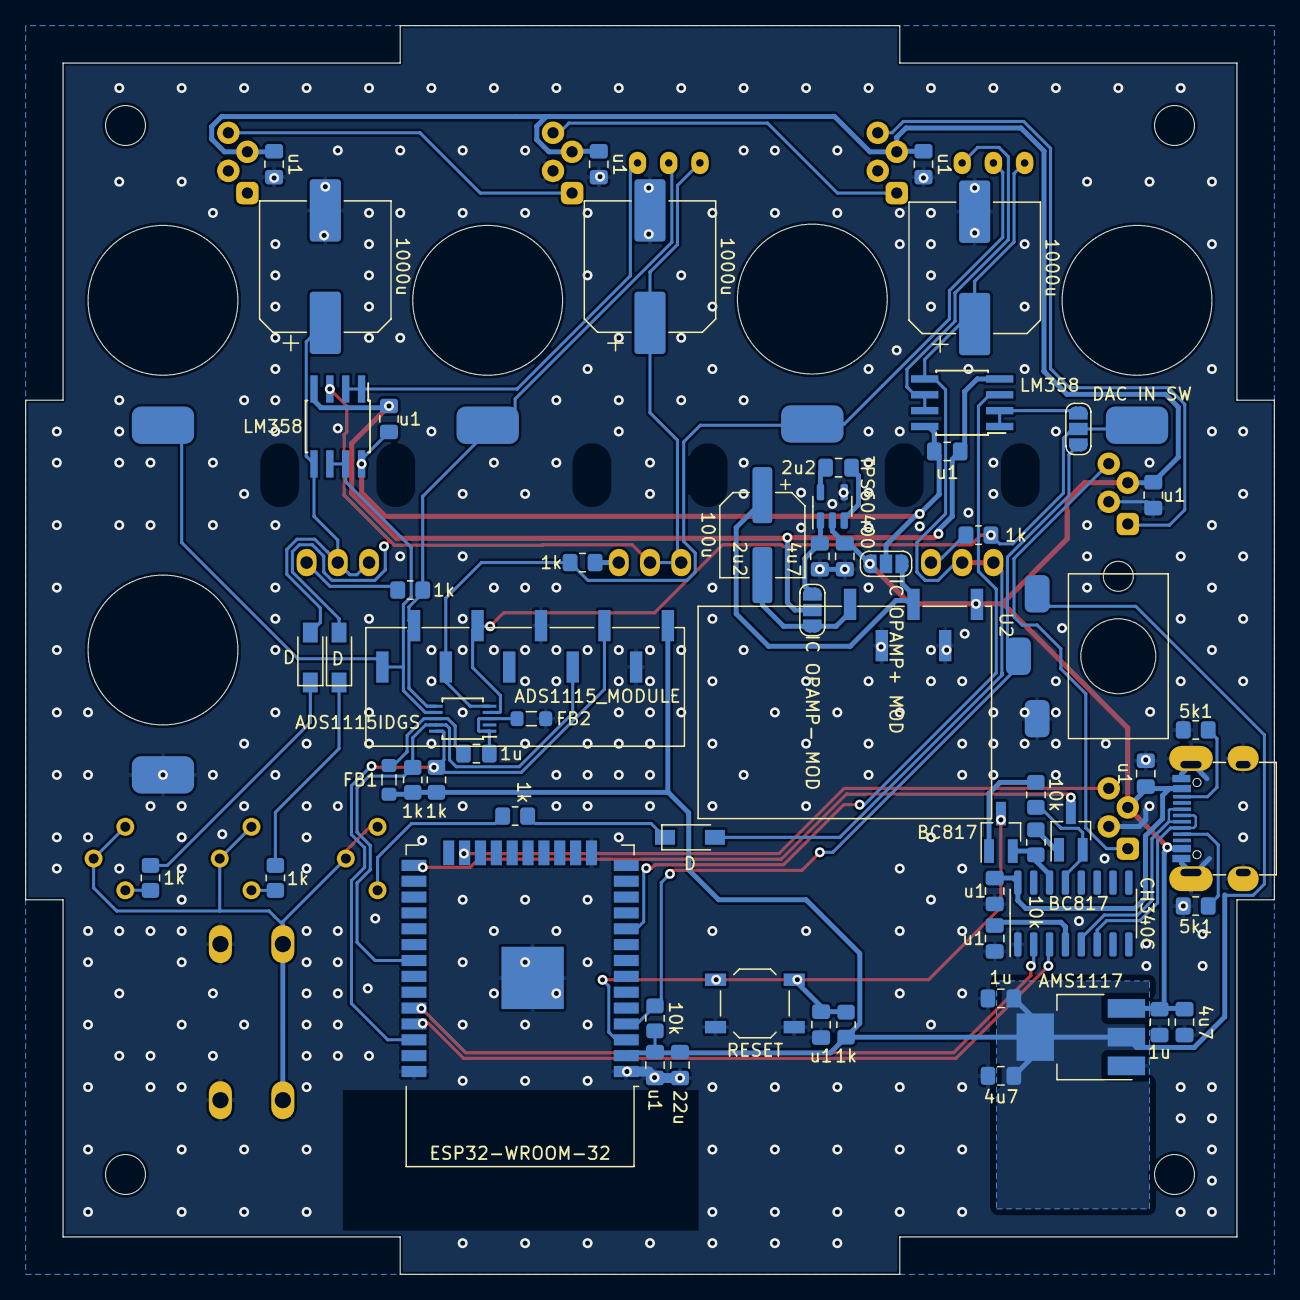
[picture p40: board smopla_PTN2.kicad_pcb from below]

Board: 2 copper layers, 100.0 x 100.0 mm, 83 parts (59 on the bottom side), 54 nets.

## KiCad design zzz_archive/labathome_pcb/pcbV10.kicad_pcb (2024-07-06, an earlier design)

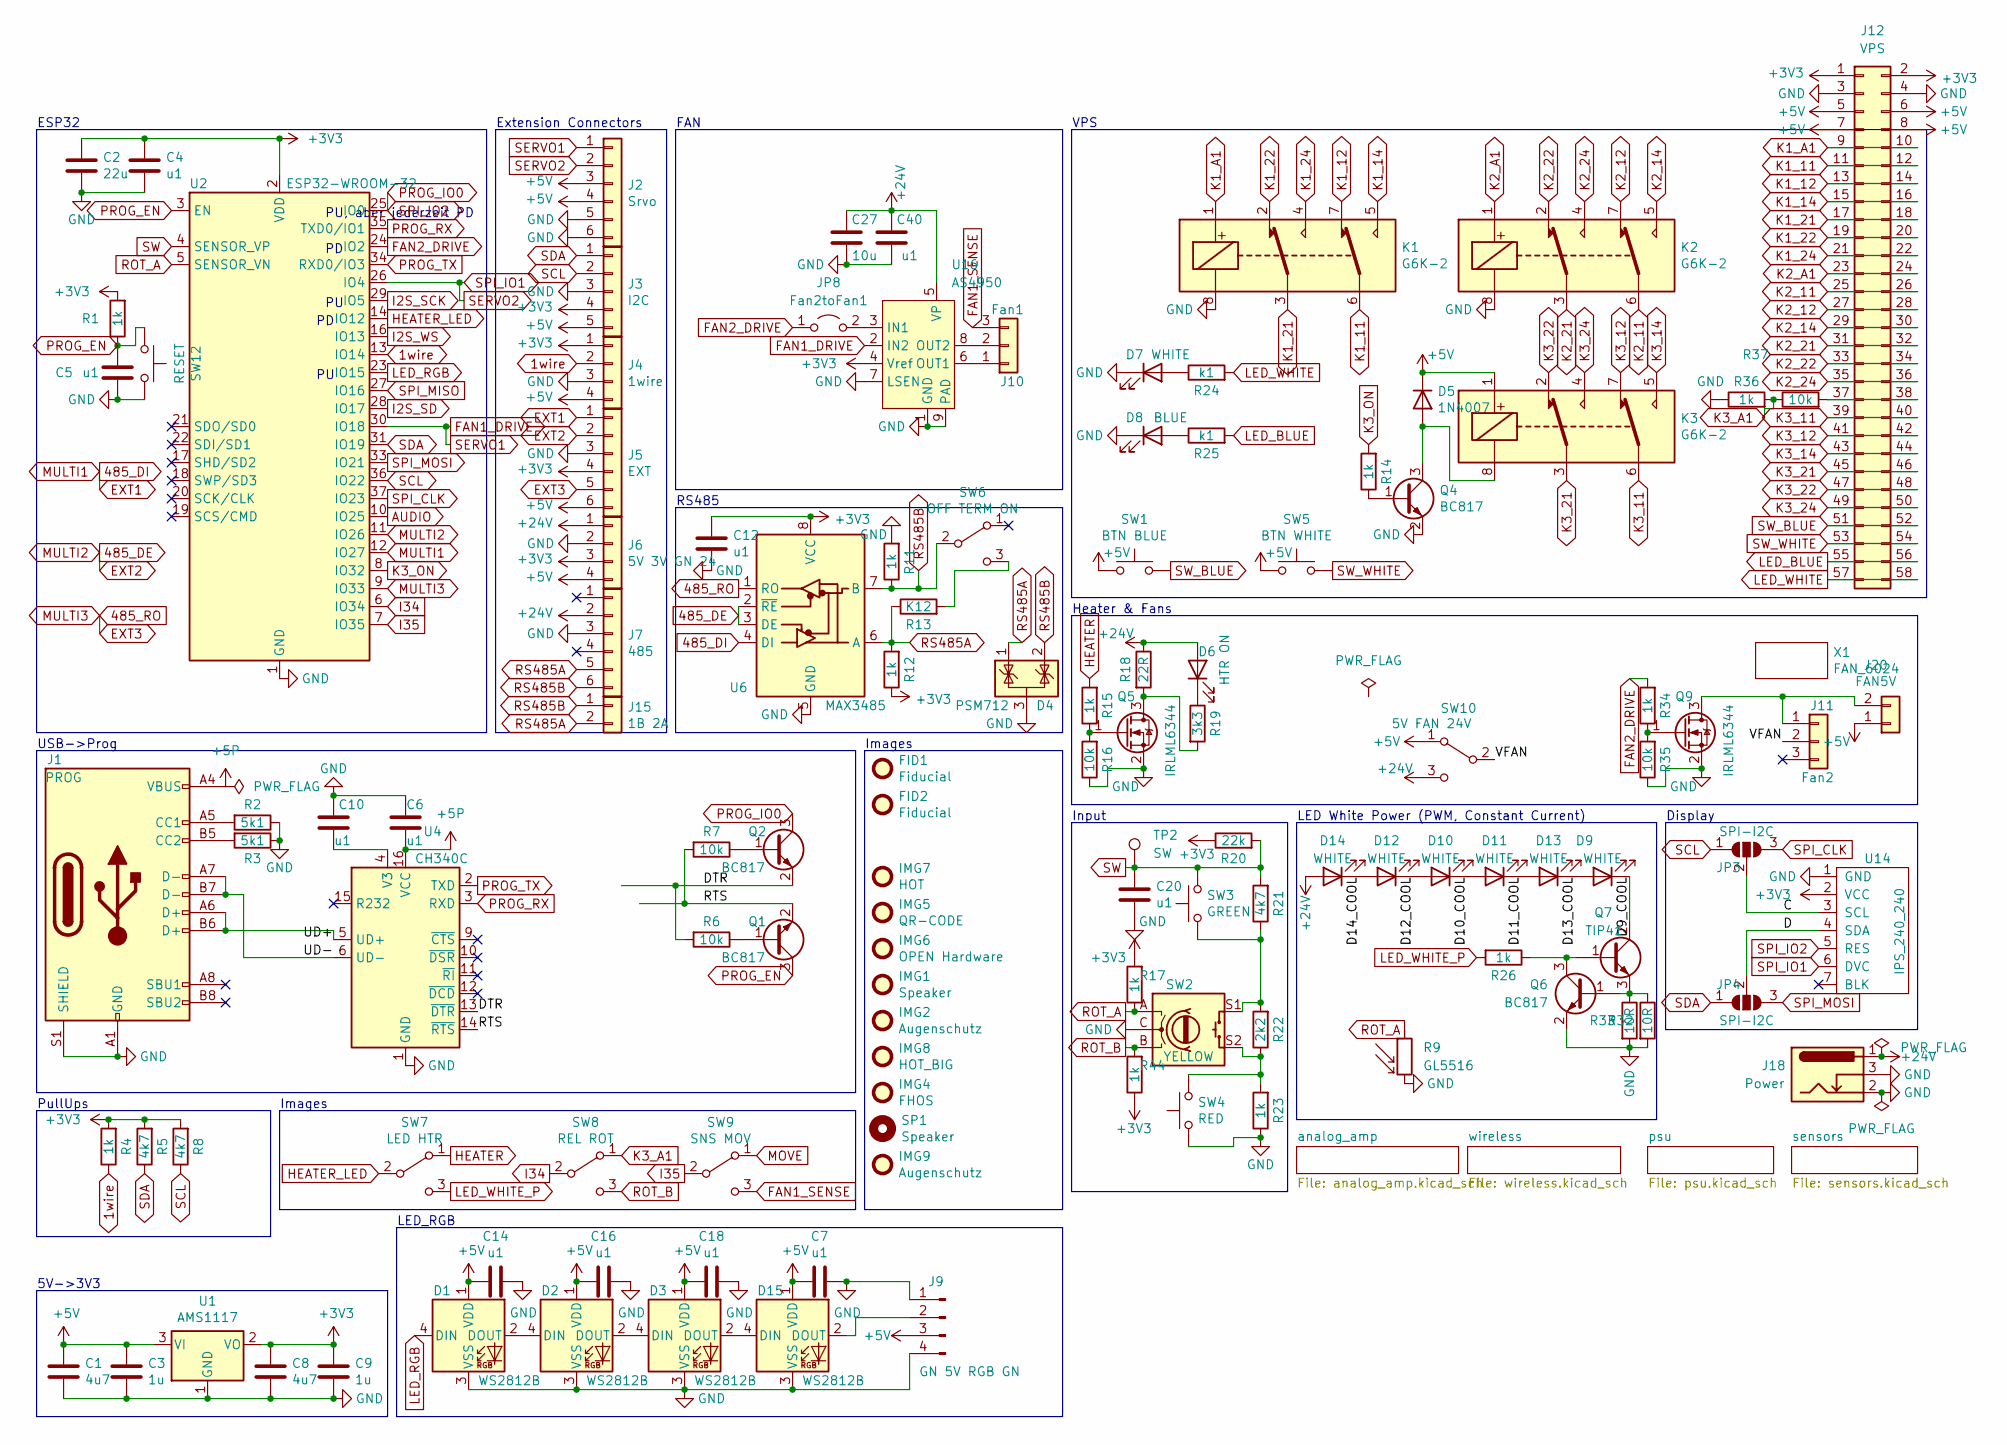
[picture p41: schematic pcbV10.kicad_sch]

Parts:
C1, C8: 4u7; C_0603_1608Metric
C2: 22u; C_0603_1608Metric
C3, C9: 1u; C_0603_1608Metric
C4, C5, C6, C7, C10, C12, C14, C16, C18, C20, C40: u1; C_0603_1608Metric
C27: 10u; C_1206_3216Metric
D1, D2, D3, D15: WS2812B; LED_WS2812B_PLCC4_5.0x5.0mm_P3.2mm
D4: PSM712; SOT-23
D5: 1N4007; D_SOD-123
D6: HTR ON; LED_0805_2012Metric
D7: WHITE; D_0805_2012Metric
D8: BLUE; D_0805_2012Metric
D9, D10, D11, D12, D13, D14: WHITE; LED_PLCC_2835
FID1, FID2: Fiducial; Fiducial_1mm_Mask2mm
IMG1: Speaker; speaker
IMG2: Augenschutz; googles
IMG4: FHOS; LOGO_FHOS_80mm
IMG5: QR-CODE; QR_CODE_smopla_de
IMG6: OPEN Hardware; OSHW-Logo2_7.3x6mm_SilkScreen
IMG7: HOT; hot
IMG8: HOT_BIG; hot_big
IMG9: Augenschutz; qwiic
J1: PROG; USB_C_Receptacle_HRO_TYPE-C-31-M-12_IMPROVED
J2: Srvo; PinHeader_2x03_P2.54mm_Vertical
J3: I2C; JST_XH_B5B-XH-AM_1x05_P2.50mm_Vertical
J4: 1wire; JST_XH_B4B-XH-AM_1x04_P2.50mm_Vertical
J5: EXT; JST_XH_B6B-XH-AM_1x06_P2.50mm_Vertical
J6: 5V 3V GN 24; JST_XH_B4B-XH-AM_1x04_P2.50mm_Vertical
J7: 485; WR_MJ_Modular_Jack_Vertical_Plastic_6P6C
J9: GN 5V RGB GN; PinHeader_1x04_P2.54mm_Vertical
J10: Fan1; FanPinHeader_1x03_P2.54mm_Vertical
J11: Fan2; FanPinHeader_1x03_P2.54mm_Vertical
J12: VPS; PinHeader_2x29_P2.54mm_Vertical
J15: 1B 2A; PhoenixContact_MCV_1,5_2-G-3.81_1x02_P3.81mm_Vertical
J18: Power; BarrelJack_Horizontal
J20: FAN5V; JST_XH_B2B-XH-A_1x02_P2.50mm_Vertical
JP3, JP4: SPI-I2C; SolderJumper-3_P1.3mm_Open_RoundedPad1.0x1.5mm_NumberLabels
JP8: Fan2toFan1; SolderJumper-2_P1.3mm_Open_RoundedPad1.0x1.5mm
K1, K2, K3: G6K-2; Relay_DPDT_Omron_G6K-2F-Y
Q1, Q2, Q4, Q6: BC817; SOT-23
Q5, Q9: IRLML6344; SOT-23
Q7: TIP41; TO-220-3_Horizontal_TabUp
R1, R4, R11, R12, R14, R15, R17, R23, R26, R34, R36, R44: 1k; R_0603_1608Metric
R2, R3: 5k1; R_0603_1608Metric
R5, R8, R21: 4k7; R_0603_1608Metric
R6, R7, R16, R35, R37: 10k; R_0603_1608Metric
R9: GL5516; R_LDR_5.1x4.3mm_P3.4mm_Vertical
R13: K12; R_0603_1608Metric
R18: 22R; Resistor_100W
R19: 3k3; R_1206_3216Metric
R20: 22k; R_0603_1608Metric
R22: 2k2; R_0603_1608Metric
R24, R25: k1; R_0603_1608Metric
R32, R33: 10R; R_1206_3216Metric
SP1: Speaker; SPEAKER_2415
SW1: BTN BLUE; SW_Push_1P1T_NO_CK_PTS125Sx43PSMTR
SW2: YELLOW; RotaryEncoder_Alps_EC11E-Switch_Vertical_H20mm
SW3: GREEN; SW_Push_1P1T_NO_CK_PTS125Sx43PSMTR
SW4: RED; SW_Push_1P1T_NO_CK_PTS125Sx43PSMTR
SW5: BTN WHITE; SW_Push_1P1T_NO_CK_PTS125Sx43PSMTR
SW6: OFF TERM ON; Switch_SS12D00
SW7: LED HTR; Switch_SS12D00
SW8: REL ROT; Switch_SS12D00
SW9: SNS MOV; Switch_SS12D00
SW10: 5V FAN 24V; Switch_SS12D00
SW12: RESET; SW_SPST_TL3342
TP2: SW; TestPoint_THTPad_1.0x1.0mm_Drill0.5mm
U1: AMS1117; SOT-223-3_TabPin2
U2: ESP32-WROOM-32
U4: CH340C; SOIC-16_3.9x9.9mm_P1.27mm
U6: MAX3485; SOIC-8_3.9x4.9mm_P1.27mm
U14: IPS_240_240; IPS_240_240_1.3
U16: AS4950; SOIC-8-1EP_3.9x4.9mm_P1.27mm_EP2.29x3mm_ThermalVias
X1: FAN_6024

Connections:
1wire: J4.2, R4.1, U2.13 (IO14); also elsewhere on the board
485_DE: J5.2, U2.11 (IO26), U6.2 (~RE), U6.3 (DE)
485_DI: J5.1, U2.12 (IO27), U6.4 (DI)
485_RO: J5.5, U2.9 (IO33), U6.1 (RO)
+3V3: C2.1, C4.2, C8.2, C9.1, C12.2, J3.4, J4.1, J5.4, J6.3, J12.1, J12.2, R1.2, R4.2, R5.2, R8.2, R12.1, R17.2, R20.1, R44.1, U1.2 (VO), U2.2 (VDD), U6.8 (VCC), U14.2 (VCC), U16.4 (Vref); also elsewhere on the board
+5P: C6.1, J1.A4 (VBUS), J1.A9 (VBUS), J1.B4 (VBUS), J1.B9 (VBUS), U4.16 (VCC); also elsewhere on the board
+5V: C1.2, C3.1, C7.2, C14.2, C16.2, C18.2, D1.1 (VDD), D2.1 (VDD), D3.1 (VDD), D5.1 (K), D15.1 (VDD), J2.3, J2.4, J3.5, J4.4, J5.6, J6.4, J9.3, J12.5, J12.6, J12.7, J12.8, J20.1, K3.1, SW1.1, SW5.1, SW10.1 (A), U1.3 (VI); also elsewhere on the board
+24V: C27.2, C40.2, D6.2 (A), D14.2 (A), J6.1, J7.2, J18.1, R18.1, SW10.3 (C), U16.5 (VP); also elsewhere on the board
/C: JP3.2 (C), U14.3 (SCL)
/D: JP4.2 (C), U14.4 (SDA)
/D9_COOL: D9.1 (K), Q7.2 (C)
/D10_COOL: D10.1 (K), D11.2 (A)
/D11_COOL: D11.1 (K), D13.2 (A)
/D12_COOL: D10.2 (A), D12.1 (K)
/D13_COOL: D9.2 (A), D13.1 (K)
/D14_COOL: D12.2 (A), D14.1 (K)
/DTR: Q2.2 (E), R6.2, U4.13 (~DTR)
/RTS: Q1.2 (E), R7.2, U4.14 (~RTS)
/UD+: J1.A6 (D+), J1.B6 (D+), U4.5 (UD+)
/UD-: J1.A7 (D-), J1.B7 (D-), U4.6 (UD-)
/VFAN: J11.2, SW10.2 (B)
AUDIO: U2.10 (IO25); also elsewhere on the board
FAN1_DRIVE: J2.1, U2.30 (IO18), U16.2 (IN2)
FAN1_SENSE: J10.3, SW9.3 (C); also elsewhere on the board
FAN2_DRIVE: JP8.1 (A), R34.2, U2.24 (IO2)
GND: C1.1, C2.2, C3.2, C4.1, C5.1, C6.2, C7.1, C8.1, C9.2, C10.2, C12.1, C14.1, C16.1, C18.1, C20.1, C27.1, C40.1, D1.3 (VSS), D2.3 (VSS), D3.3 (VSS), D4.3 (A), D7.1 (K), D8.1 (K), D15.3 (VSS), J1.A1 (GND), J1.A12 (GND), J1.B1 (GND), J1.B12 (GND), J1.S1 (SHIELD), J2.5, J2.6, J3.3, J4.3, J5.3, J6.2, J7.3, J9.1, J9.4, J12.3, J12.4, J18.2, J18.3, K1.8, K2.8, Q4.2 (E), Q5.2 (S), Q6.2 (E), Q9.2 (S), R2.1, R3.1, R9.2, R11.2, R16.1, R23.1, R32.2, R33.2, R35.1, R36.1, SW2.C, SW4.1, SW12.2, U1.1 (GND), U2.1 (GND), U2.15 (GND), U2.38 (GND), U2.39 (GND), U4.1 (GND), U6.5 (GND), U14.1 (GND), U16.1 (GND), U16.7 (LSEN), U16.9 (PAD); also elsewhere on the board
HEATER: R15.2, SW7.1 (A)
HEATER_LED: SW7.2 (B), U2.14 (IO12)
I2S_SCK: U2.29 (IO5); also elsewhere on the board
I2S_SD: U2.28 (IO17); also elsewhere on the board
I2S_WS: U2.16 (IO13); also elsewhere on the board
I34: SW8.2 (B), U2.6 (IO34)
I35: SW9.2 (B), U2.7 (IO35)
K1_11: J12.11, J12.12, K1.6
K1_12: J12.13, J12.14, K1.7
K1_14: J12.15, J12.16, K1.5
K1_21: J12.17, J12.18, K1.3
K1_22: J12.19, J12.20, K1.2
K1_24: J12.21, J12.22, K1.4
K1_A1: J12.9, J12.10, K1.1
K2_11: J12.25, J12.26, K2.6
K2_12: J12.27, J12.28, K2.7
K2_14: J12.29, J12.30, K2.5
K2_21: J12.31, J12.32, K2.3
K2_22: J12.33, J12.34, K2.2
K2_24: J12.35, J12.36, K2.4
K2_A1: J12.23, J12.24, K2.1
K3_11: J12.39, J12.40, K3.6
K3_12: J12.41, J12.42, K3.7
K3_14: J12.43, J12.44, K3.5
K3_21: J12.45, J12.46, K3.3
K3_22: J12.47, J12.48, K3.2
K3_24: J12.49, J12.50, K3.4
K3_A1: R36.2, R37.1, SW8.1 (A)
K3_ON: R14.2, U2.8 (IO32)
LED_BLUE: J12.55, J12.56, R25.2
LED_RGB: D1.4 (DIN), U2.23 (IO15)
LED_WHITE: J12.57, J12.58, R24.2
LED_WHITE_P: R26.2, SW7.3 (C)
MOVE: SW9.1 (A); also elsewhere on the board
unnamed: C10.1, U4.4 (V3)
unnamed: D1.2 (DOUT), D2.4 (DIN)
unnamed: D2.2 (DOUT), D3.4 (DIN)
unnamed: D5.2 (A), K3.8, Q4.3 (C)
unnamed: D6.1 (K), R19.1
unnamed: D7.2 (A), R24.1
unnamed: D8.2 (A), R25.1
unnamed: D15.2 (DOUT), J9.2
unnamed: D3.2 (DOUT), D15.4 (DIN)
unnamed: J1.A5 (CC1), R2.2
unnamed: J1.B5 (CC2), R3.2
unnamed: J10.1, U16.6 (OUT1)
unnamed: J10.2, U16.8 (OUT2)
unnamed: J11.1, J20.2, Q9.3 (D)
unnamed: J12.37, J12.38, R37.2
unnamed: JP8.2 (B), U16.3 (IN1)
unnamed: Q1.1 (B), R6.1
unnamed: Q2.1 (B), R7.1
unnamed: Q4.1 (B), R14.1
unnamed: Q5.1 (G), R15.1, R16.2
unnamed: Q5.3 (D), R18.2, R19.2
unnamed: Q6.1 (B), Q7.3 (E), R32.1, R33.1
unnamed: Q6.3 (C), Q7.1 (B), R26.1
unnamed: Q9.1 (G), R34.1, R35.2
unnamed: R13.2, SW6.3 (C)
unnamed: R21.1, R22.2, SW2.S1, SW3.1
unnamed: R22.1, R23.2, SW2.S2, SW4.2
PROG_EN: C5.2, Q1.3 (C), R1.1, SW12.1, U2.3 (EN)
PROG_IO0: Q2.3 (C), U2.25 (IO0), U14.5 (RES); also elsewhere on the board
PROG_RX: U2.35 (TXD0/IO1), U4.3 (RXD)
PROG_TX: U2.34 (RXD0/IO3), U4.2 (TXD)
ROT_A: R9.1, R17.1, SW2.A, U2.5 (SENSOR_VN)
ROT_B: R44.2, SW2.B, SW8.3 (C)
RS485A: D4.1 (K), J7.5, J15.2, R12.2, R13.1, U6.6 (A)
RS485B: D4.2 (K), J7.6, J15.1, R11.1, SW6.2 (B), U6.7 (B)
SCL: J3.2, JP3.1 (A), R8.1, U2.36 (IO22); also elsewhere on the board
SDA: J3.1, JP4.1 (A), R5.1, U2.31 (IO19); also elsewhere on the board
SERVO2: J2.2, U2.26 (IO4), U14.6 (DVC); also elsewhere on the board
SPI_CLK: JP3.3 (B), U2.37 (IO23); also elsewhere on the board
SPI_MISO: U2.27 (IO16); also elsewhere on the board
SPI_MOSI: JP4.3 (B), U2.33 (IO21); also elsewhere on the board
SW: C20.2, R20.2, R21.2, SW3.2, TP2.1, U2.4 (SENSOR_VP)
SW_BLUE: J12.51, J12.52, SW1.2
SW_WHITE: J12.53, J12.54, SW5.2

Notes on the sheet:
LED White Power (PWM, Constant Current)
LED_RGB
Display
USB->Prog
Images
PU, aber jederzeit PD
Input
FAN
VPS
PullUps
5V->3V3
RS485
Heater & Fans
Extension Connectors
ESP32

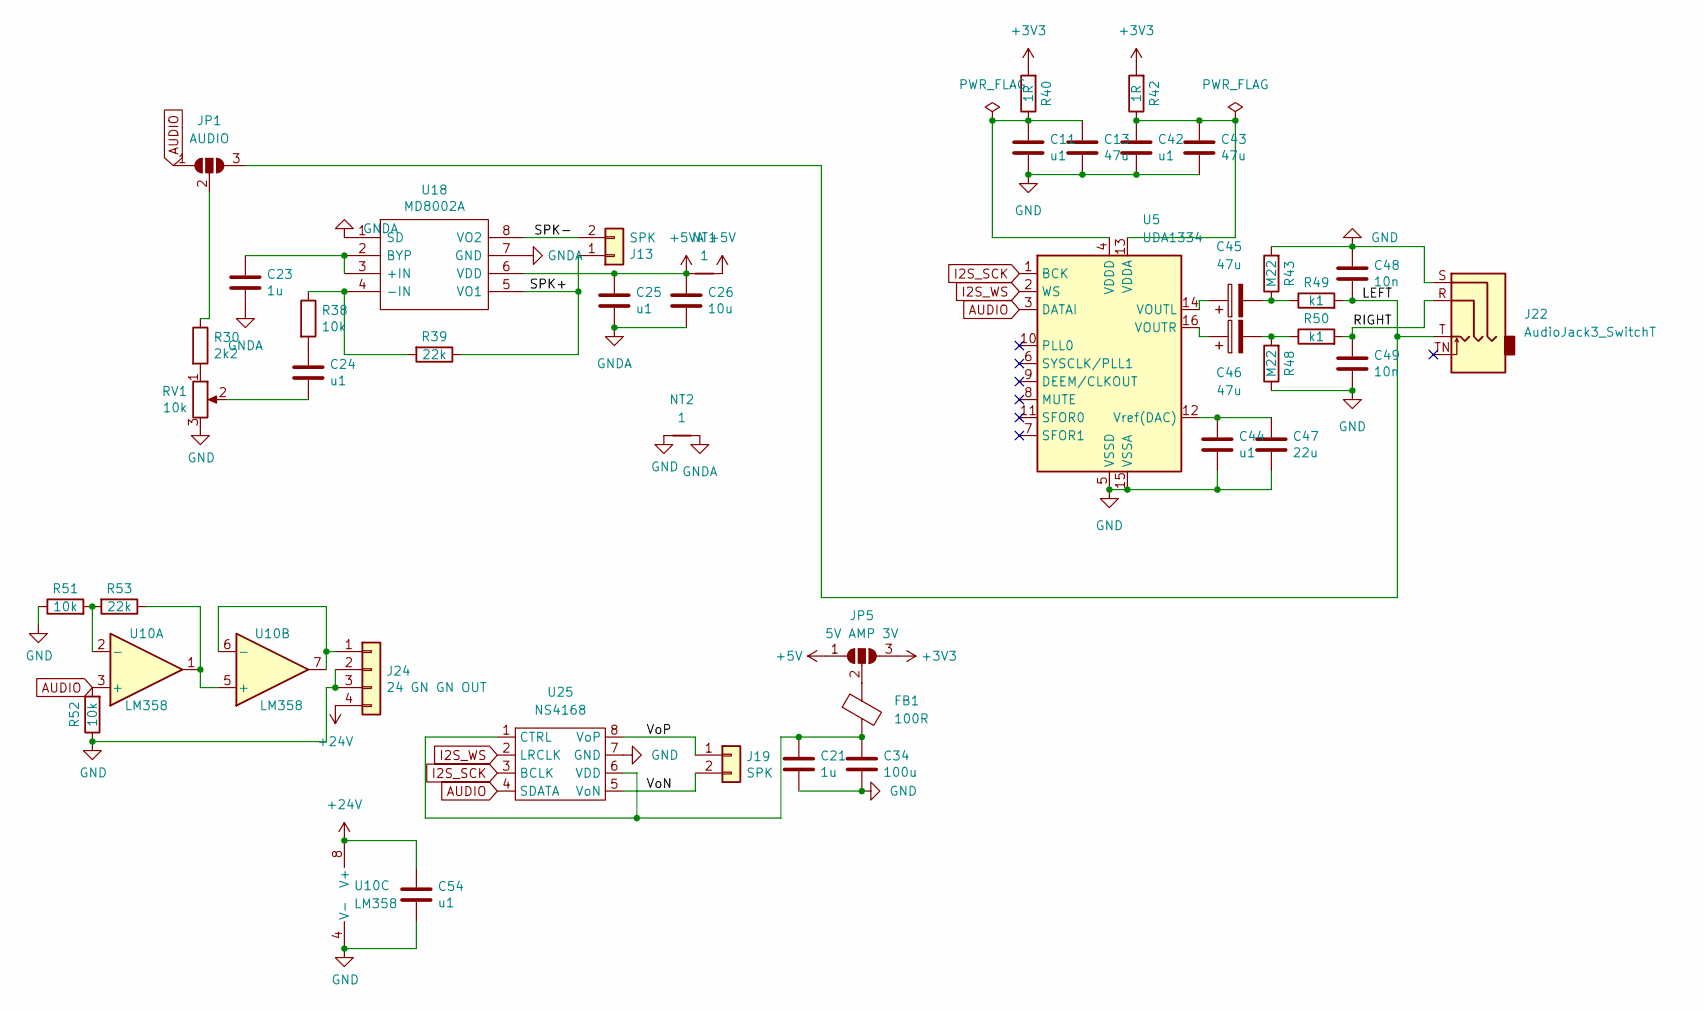
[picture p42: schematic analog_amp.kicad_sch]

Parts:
C11, C24, C25, C42, C44, C54: u1; C_0603_1608Metric
C13, C43: 47u; C_0603_1608Metric
C21: 1u; C_0805_2012Metric_Pad1.18x1.45mm_HandSolder
C23: 1u; C_0603_1608Metric
C26: 10u; C_0603_1608Metric
C34: 100u; C_1206_3216Metric_Pad1.33x1.80mm_HandSolder
C45, C46: 47u; CP_Elec_5x5.4
C47: 22u; C_0603_1608Metric
C48: 10n; C_0603_1608Metric
C49: 10n; C_0402_1005Metric
FB1: 100R; L_0805_2012Metric
J13, J19: SPK; SolderWire-0.1sqmm_1x02_P3.6mm_D0.4mm_OD1mm
J22: AudioJack3_SwitchT; PJ-327A
J24: 24 GN GN OUT; JST_XH_S4B-XH-A_1x04_P2.50mm_Horizontal
JP1: AUDIO; SolderJumper-3_P1.3mm_Open_RoundedPad1.0x1.5mm_NumberLabels
JP5: 5V AMP 3V; SolderJumper-3_P1.3mm_Open_RoundedPad1.0x1.5mm_NumberLabels
NT1, NT2: 1; NetTie-2_SMD_Pad0.5mm
R30: 2k2; R_0603_1608Metric
R38, R51, R52: 10k; R_0603_1608Metric
R39, R53: 22k; R_0603_1608Metric
R40, R42: 1R; R_0603_1608Metric
R43: M22; R_0603_1608Metric
R48: M22; R_0402_1005Metric
R49: k1; R_0603_1608Metric
R50: k1; R_0402_1005Metric
RV1: 10k; Potentiometer_Alps_RK09K_Single_Vertical
U5: UDA1334; SSOP-16_4.4x5.2mm_P0.65mm
U10: LM358; SOIC-8_3.9x4.9mm_P1.27mm
U18: MD8002A; SOIC-8_3.9x4.9mm_P1.27mm; Manufacturer_Part_Number MD8002A
U25: NS4168; SOIC-8_3.9x4.9mm_Pitch1.27mm_pad_handsolder

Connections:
+3V3: JP5.3 (B), R40.2, R42.2; also elsewhere on the board
+5V: JP5.1 (A), NT1.2; also elsewhere on the board
+5VA: C25.1, C26.1, NT1.1, U18.6 (VDD)
+24V: C54.2, J24.4, U10.8 (V+); also elsewhere on the board
/analog_amp/LEFT: C48.1, J22.T, JP1.3 (B), R49.2
/analog_amp/RIGHT: C49.2, J22.R, R50.2
/analog_amp/SPK+: J13.1, R39.1, U18.5 (VO1)
/analog_amp/SPK-: J13.2, U18.8 (VO2)
/analog_amp/VoN: J19.2, U25.5 (VoN)
/analog_amp/VoP: J19.1, U25.8 (VoP)
AUDIO: JP1.1 (A), R52.2, U5.3 (DATAI), U10.3 (+), U25.4 (SDATA); also elsewhere on the board
GND: C11.1, C13.1, C21.2, C34.2, C42.1, C43.1, C44.1, C47.1, C48.2, C49.1, C54.1, J22.S, J24.2, J24.3, NT2.1, R43.2, R48.1, R51.1, R52.1, RV1.3, U5.5 (VSSD), U5.15 (VSSA), U10.4 (V-), U25.7 (GND); also elsewhere on the board
GNDA: C23.2, C25.2, C26.2, NT2.2, U18.1 (SD), U18.7 (GND)
I2S_SCK: U5.1 (BCK), U25.3 (BCLK); also elsewhere on the board
I2S_WS: U5.2 (WS), U25.2 (LRCLK); also elsewhere on the board
unnamed: C11.2, C13.2, R40.1, U5.4 (VDDD)
unnamed: C21.1, C34.1, FB1.2, U25.1 (CTRL), U25.6 (VDD)
unnamed: C23.1, U18.2 (BYP), U18.3 (+IN)
unnamed: C24.1, R38.2
unnamed: C24.2, RV1.2
unnamed: C42.2, C43.2, R42.1, U5.13 (VDDA)
unnamed: C44.2, C47.2, U5.12 (Vref(DAC))
unnamed: C45.1, U5.14 (VOUTL)
unnamed: C45.2, R43.1, R49.1
unnamed: C46.1, U5.16 (VOUTR)
unnamed: C46.2, R48.2, R50.1
unnamed: FB1.1, JP5.2 (C)
unnamed: J24.1, U10.6 (-), U10.7
unnamed: JP1.2 (C), R30.1
unnamed: R30.2, RV1.1
unnamed: R38.1, R39.2, U18.4 (-IN)
unnamed: R51.2, R53.2, U10.2 (-)
unnamed: R53.1, U10.1, U10.5 (+)

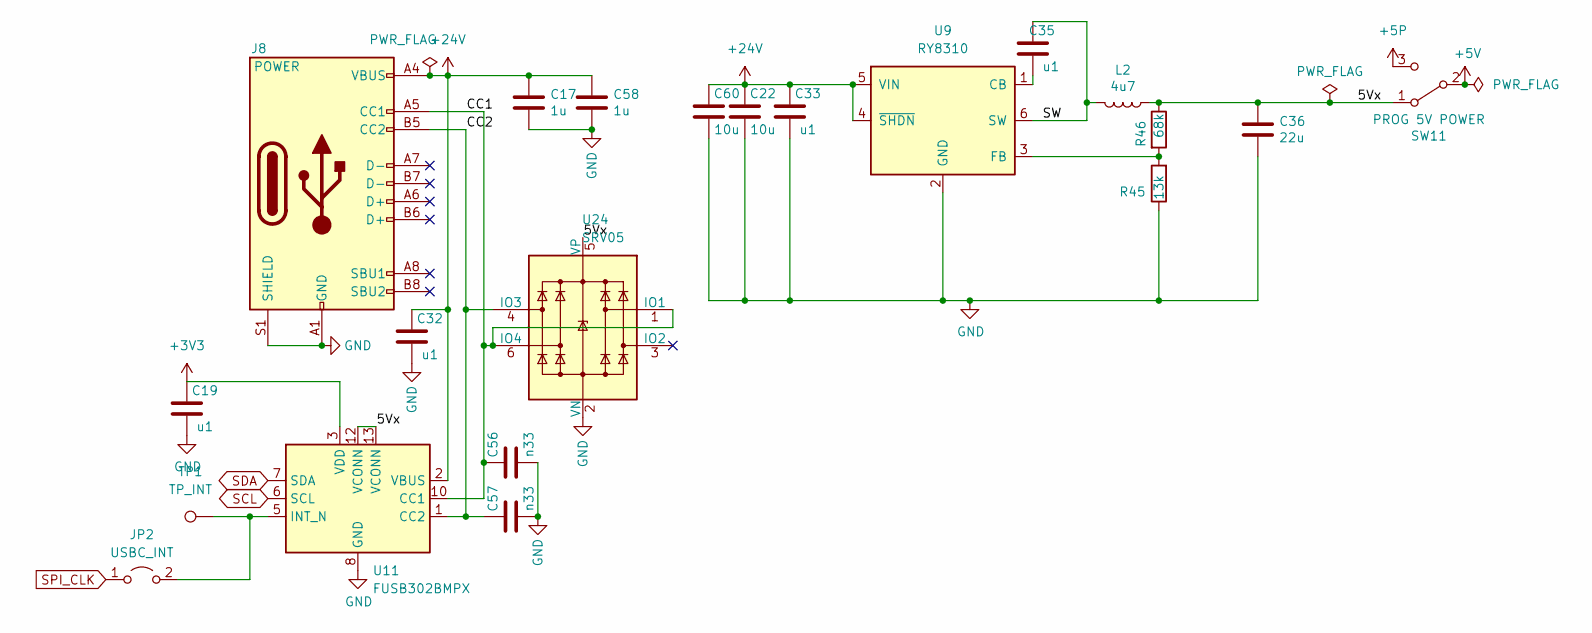
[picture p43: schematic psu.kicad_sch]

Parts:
C17, C58: 1u; C_1206_3216Metric
C19, C32, C33, C35: u1; C_0603_1608Metric
C22, C60: 10u; C_1206_3216Metric
C36: 22u; C_0603_1608Metric
C56, C57: n33; C_0603_1608Metric
J8: POWER; USB_C_Receptacle_HRO_TYPE-C-31-M-12_IMPROVED
JP2: USBC_INT; Jumper_Trace_025x150x015
L2: 4u7; L_Abracon_ASPI-0630LR
R45: 13k; R_0603_1608Metric
R46: 68k; R_0603_1608Metric
SW11: PROG 5V POWER; Switch_SS12D00
TP1: TP_INT; TestPoint_THTPad_1.0x1.0mm_Drill0.5mm
U9: RY8310; SOT-23-6
U11: FUSB302BMPX; WQFN-14-1EP_2.5x2.5mm_P0.5mm_EP1.45x1.45mm
U24: SRV05; SOT-23-6

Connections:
+3V3: C19.2, U11.3 (VDD), U11.4 (VDD); also elsewhere on the board
+5P: SW11.3 (C); also elsewhere on the board
+5V: SW11.2 (B); also elsewhere on the board
+24V: C17.1, C22.2, C32.2, C33.2, C58.1, C60.2, J8.A4 (VBUS), J8.A9 (VBUS), J8.B4 (VBUS), J8.B9 (VBUS), U9.4 (~SHDN), U9.5 (VIN), U11.2 (VBUS); also elsewhere on the board
/psu/5Vx: C36.1, L2.1, R46.1, SW11.1 (A), U11.12 (VCONN), U11.13 (VCONN), U24.5 (VP)
/psu/CC1: C56.2, J8.A5 (CC1), U11.10 (CC1), U11.11 (CC1), U24.1 (IO1), U24.6 (IO4)
/psu/CC2: C57.2, J8.B5 (CC2), U11.1 (CC2), U11.14 (CC2), U24.4 (IO3)
/psu/SW: C35.2, L2.2, U9.6 (SW)
GND: C17.2, C19.1, C22.1, C32.1, C33.1, C36.2, C56.1, C57.1, C58.2, C60.1, J8.A1 (GND), J8.A12 (GND), J8.B1 (GND), J8.B12 (GND), J8.S1 (SHIELD), R45.1, U9.2 (GND), U11.8 (GND), U11.9 (GND), U11.15 (GND), U24.2 (VN); also elsewhere on the board
unnamed: C35.1, U9.1 (CB)
unnamed: JP2.2 (B), TP1.1, U11.5 (INT_N)
unnamed: R45.2, R46.2, U9.3 (FB)
SCL: U11.6 (SCL); also elsewhere on the board
SDA: U11.7 (SDA); also elsewhere on the board
SPI_CLK: JP2.1 (A); also elsewhere on the board

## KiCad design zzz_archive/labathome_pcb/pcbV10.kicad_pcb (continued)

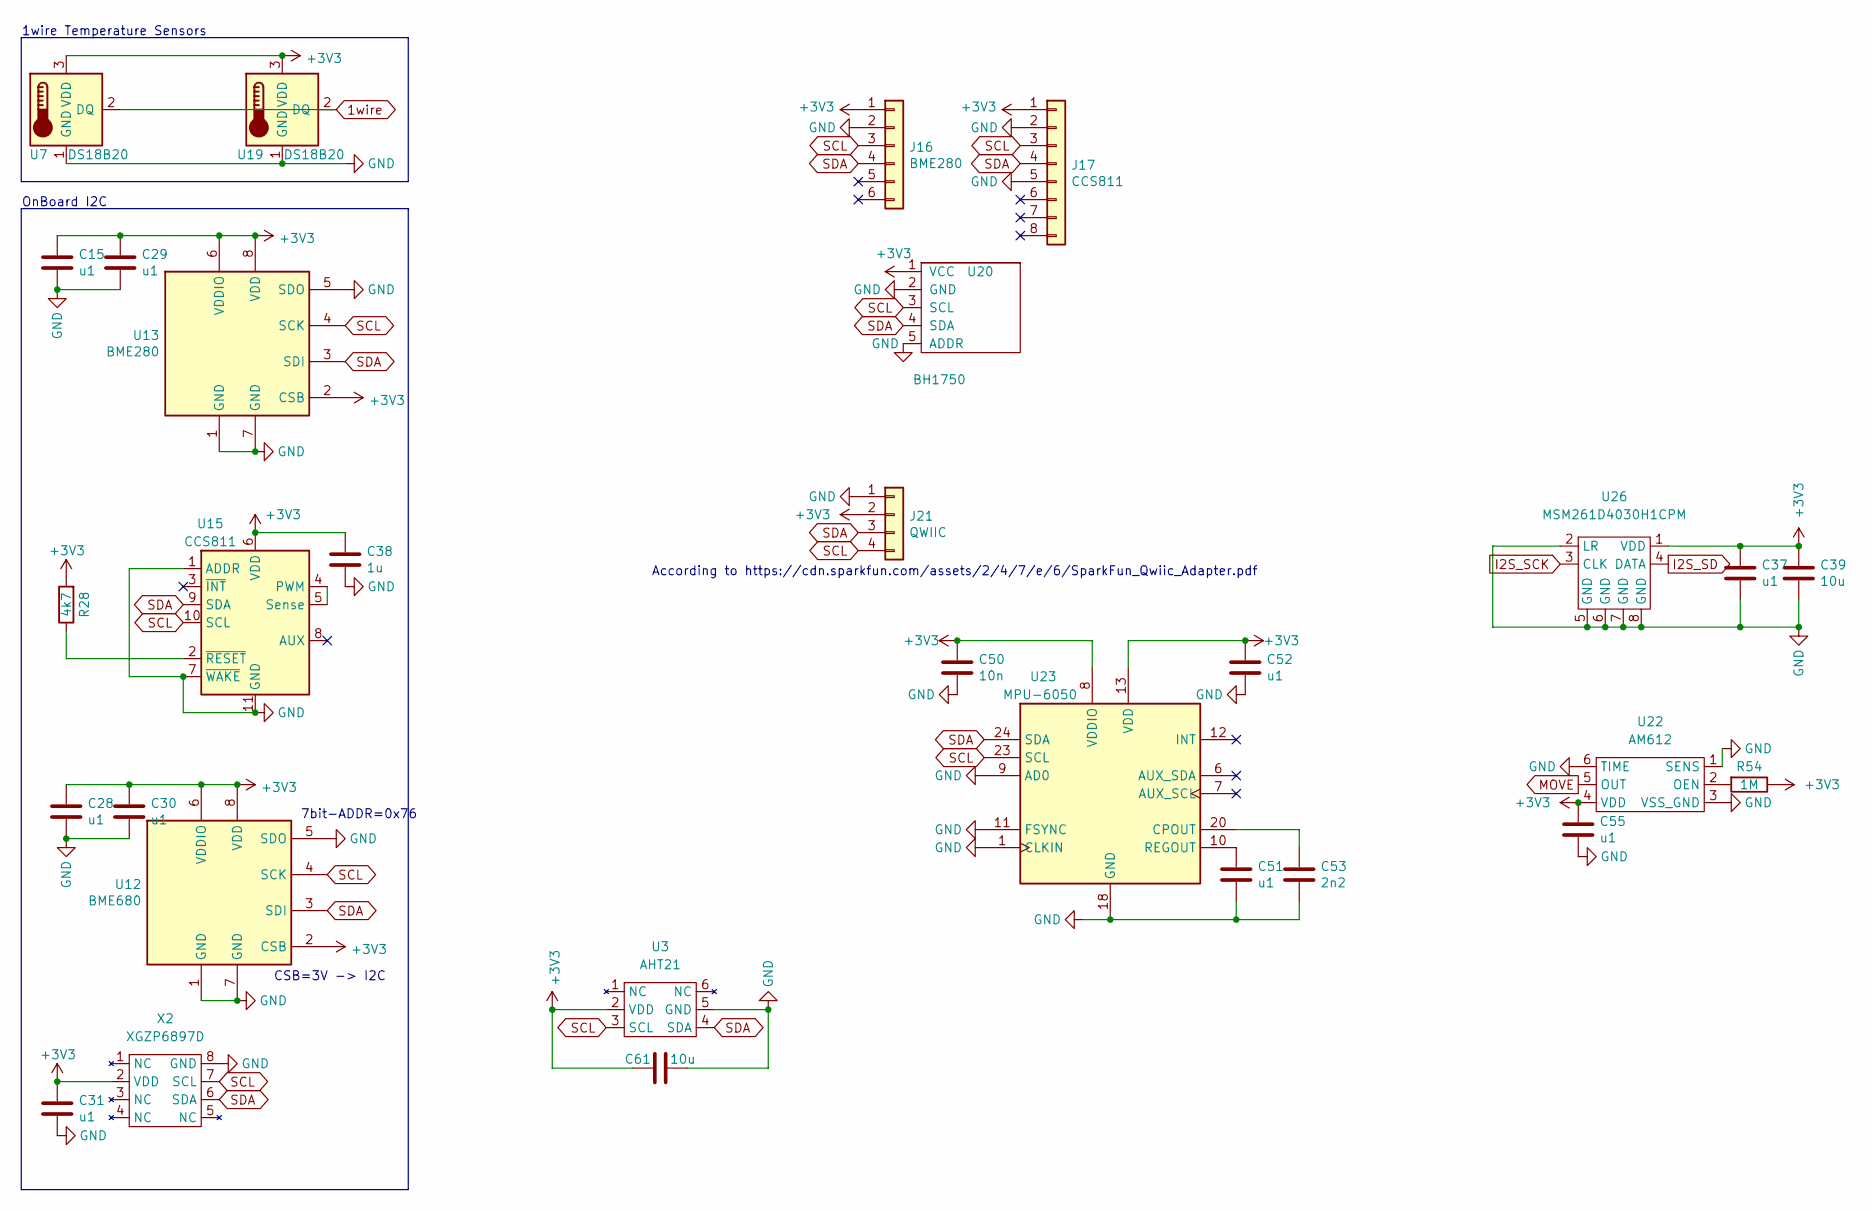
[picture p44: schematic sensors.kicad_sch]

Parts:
C15, C28, C29, C30, C31, C37, C51, C52, C55: u1; C_0603_1608Metric
C38: 1u; C_0603_1608Metric
C39, C61: 10u; C_0603_1608Metric
C50: 10n; C_0603_1608Metric
C53: 2n2; C_0603_1608Metric
J16: BME280; PinSocket_1x06_P2.54mm_Vertical
J17: CCS811; PinSocket_1x08_P2.54mm_Vertical
J21: QWIIC; JST_SH_SM04B-SRSS-TB_1x04-1MP_P1.00mm_Horizontal
R28: 4k7; R_0603_1608Metric
R54: 1M; R_0603_1608Metric
U3: AHT21
U7, U19: DS18B20; TO-92_HandSolder
U12: BME680; Bosch_LGA-8_3x3mm_P0.8mm_ClockwisePinNumbering
U13: BME280; Bosch_LGA-8_2.5x2.5mm_P0.65mm_ClockwisePinNumbering
U15: CCS811; AMS_LGA-10-1EP_2.7x4mm_P0.6mm
U20: BH1750; GY-302
U22: AM612
U23: MPU-6050; InvenSense_QFN-24_4x4mm_P0.5mm
U26: MSM261D4030H1CPM
X2: XGZP6897D

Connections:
1wire: U7.2 (DQ), U19.2 (DQ); also elsewhere on the board
+3V3: C15.2, C28.2, C29.2, C30.2, C31.2, C37.2, C38.1, C39.2, C50.2, C52.2, C55.2, C61.1, J16.1, J17.1, J21.2, R28.2, R54.1, U3.2 (VDD), U7.3 (VDD), U12.2 (CSB), U12.6 (VDDIO), U12.8 (VDD), U13.2 (CSB), U13.6 (VDDIO), U13.8 (VDD), U15.6 (VDD), U19.3 (VDD), U20.1 (VCC), U22.4 (VDD), U23.8 (VDDIO), U23.13 (VDD), U26.1 (VDD), X2.2 (VDD); also elsewhere on the board
GND: C15.1, C28.1, C29.1, C30.1, C31.1, C37.1, C38.2, C39.1, C50.1, C51.1, C52.1, C53.1, C55.1, C61.2, J16.2, J17.2, J17.5, J21.1, U3.5 (GND), U7.1 (GND), U12.1 (GND), U12.5 (SDO), U12.7 (GND), U13.1 (GND), U13.5 (SDO), U13.7 (GND), U15.1 (ADDR), U15.7 (~WAKE), U15.11 (GND), U19.1 (GND), U20.2 (GND), U20.5 (ADDR), U22.1 (SENS), U22.3 (VSS_GND), U22.6 (TIME), U23.1 (CLKIN), U23.9 (AD0), U23.11 (FSYNC), U23.18 (GND), U26.2 (LR), U26.5 (GND), U26.6 (GND), U26.7 (GND), U26.8 (GND), X2.8 (GND); also elsewhere on the board
I2S_SCK: U26.3 (CLK); also elsewhere on the board
I2S_SD: U26.4 (DATA); also elsewhere on the board
MOVE: U22.5 (OUT); also elsewhere on the board
unnamed: C51.2, U23.10 (REGOUT)
unnamed: C53.2, U23.20 (CPOUT)
unnamed: R28.1, U15.2 (~RESET)
unnamed: R54.2, U22.2 (OEN)
unnamed: U15.4 (PWM), U15.5 (Sense)
SCL: J16.3, J17.3, J21.4, U3.3 (SCL), U12.4 (SCK), U13.4 (SCK), U15.10 (SCL), U20.3 (SCL), U23.23 (SCL), X2.7 (SCL); also elsewhere on the board
SDA: J16.4, J17.4, J21.3, U3.4 (SDA), U12.3 (SDI), U13.3 (SDI), U15.9 (SDA), U20.4 (SDA), U23.24 (SDA), X2.6 (SDA); also elsewhere on the board

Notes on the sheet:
CSB=3V -> I2C
According to https://cdn.sparkfun.com/assets/2/4/7/e/6/SparkFun_Qwiic_Adapter.pdf
7bit-ADDR=0x76
1wire Temperature Sensors
OnBoard I2C

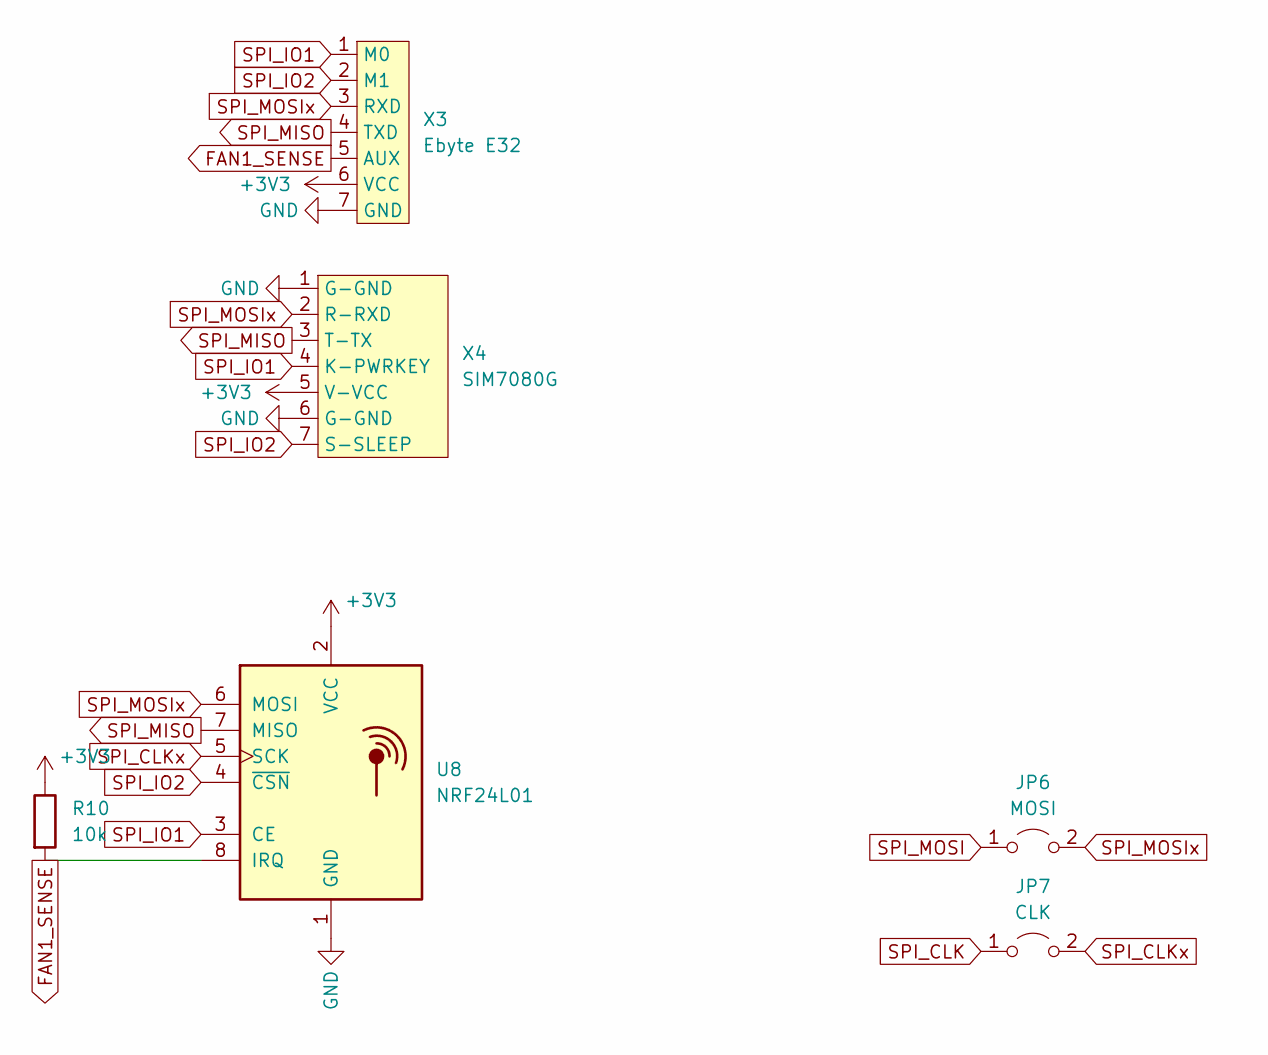
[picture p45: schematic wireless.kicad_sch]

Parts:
JP6: MOSI; SolderJumper-2_P1.3mm_Open_RoundedPad1.0x1.5mm
JP7: CLK; SolderJumper-2_P1.3mm_Open_RoundedPad1.0x1.5mm
R10: 10k; R_0402_1005Metric
U8: NRF24L01; nRF24L01_Breakout
X3: Ebyte E32; Ebyte-E32-900T20D
X4: SIM7080G; SIM7080G_AND_MODULE

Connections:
+3V3: R10.1, U8.2 (VCC), X3.6 (VCC), X4.5 (V-VCC); also elsewhere on the board
FAN1_SENSE: R10.2, U8.8 (IRQ), X3.5 (AUX); also elsewhere on the board
GND: U8.1 (GND), X3.7 (GND), X4.1 (G-GND), X4.6 (G-GND); also elsewhere on the board
PROG_IO0: U8.4 (~CSN), X3.2 (M1), X4.7 (S-SLEEP); also elsewhere on the board
SERVO2: U8.3 (CE), X3.1 (M0), X4.4 (K-PWRKEY); also elsewhere on the board
SPI_CLK: JP7.1 (A); also elsewhere on the board
SPI_CLKx: JP7.2 (B), U8.5 (SCK)
SPI_MISO: U8.7 (MISO), X3.4 (TXD), X4.3 (T-TX); also elsewhere on the board
SPI_MOSI: JP6.1 (A); also elsewhere on the board
SPI_MOSIx: JP6.2 (B), U8.6 (MOSI), X3.3 (RXD), X4.2 (R-RXD)

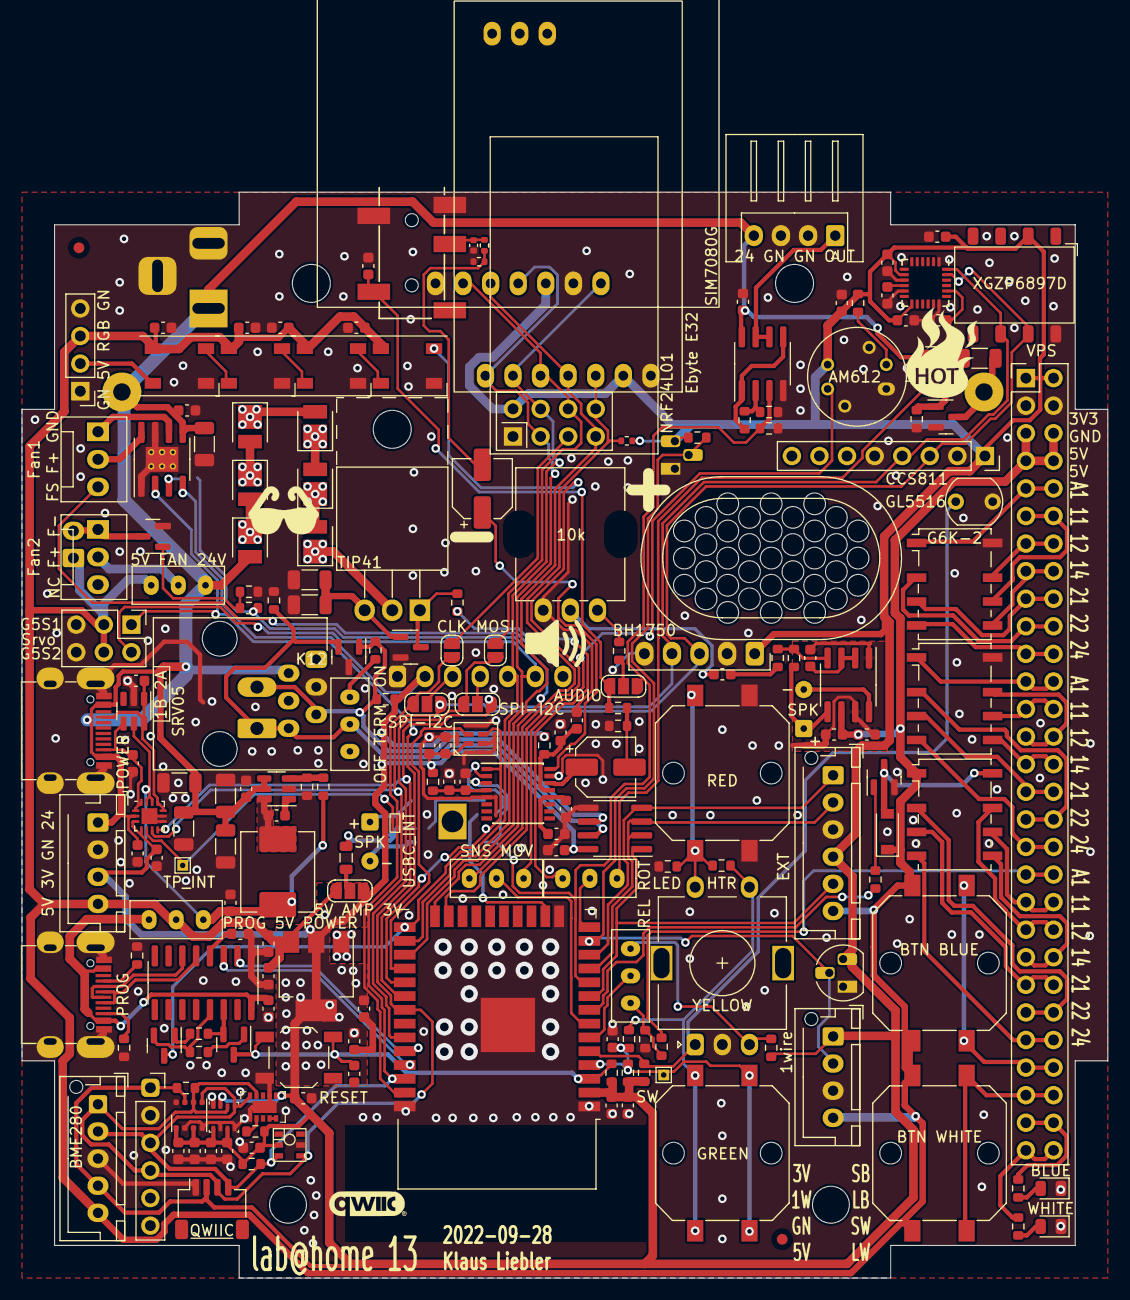
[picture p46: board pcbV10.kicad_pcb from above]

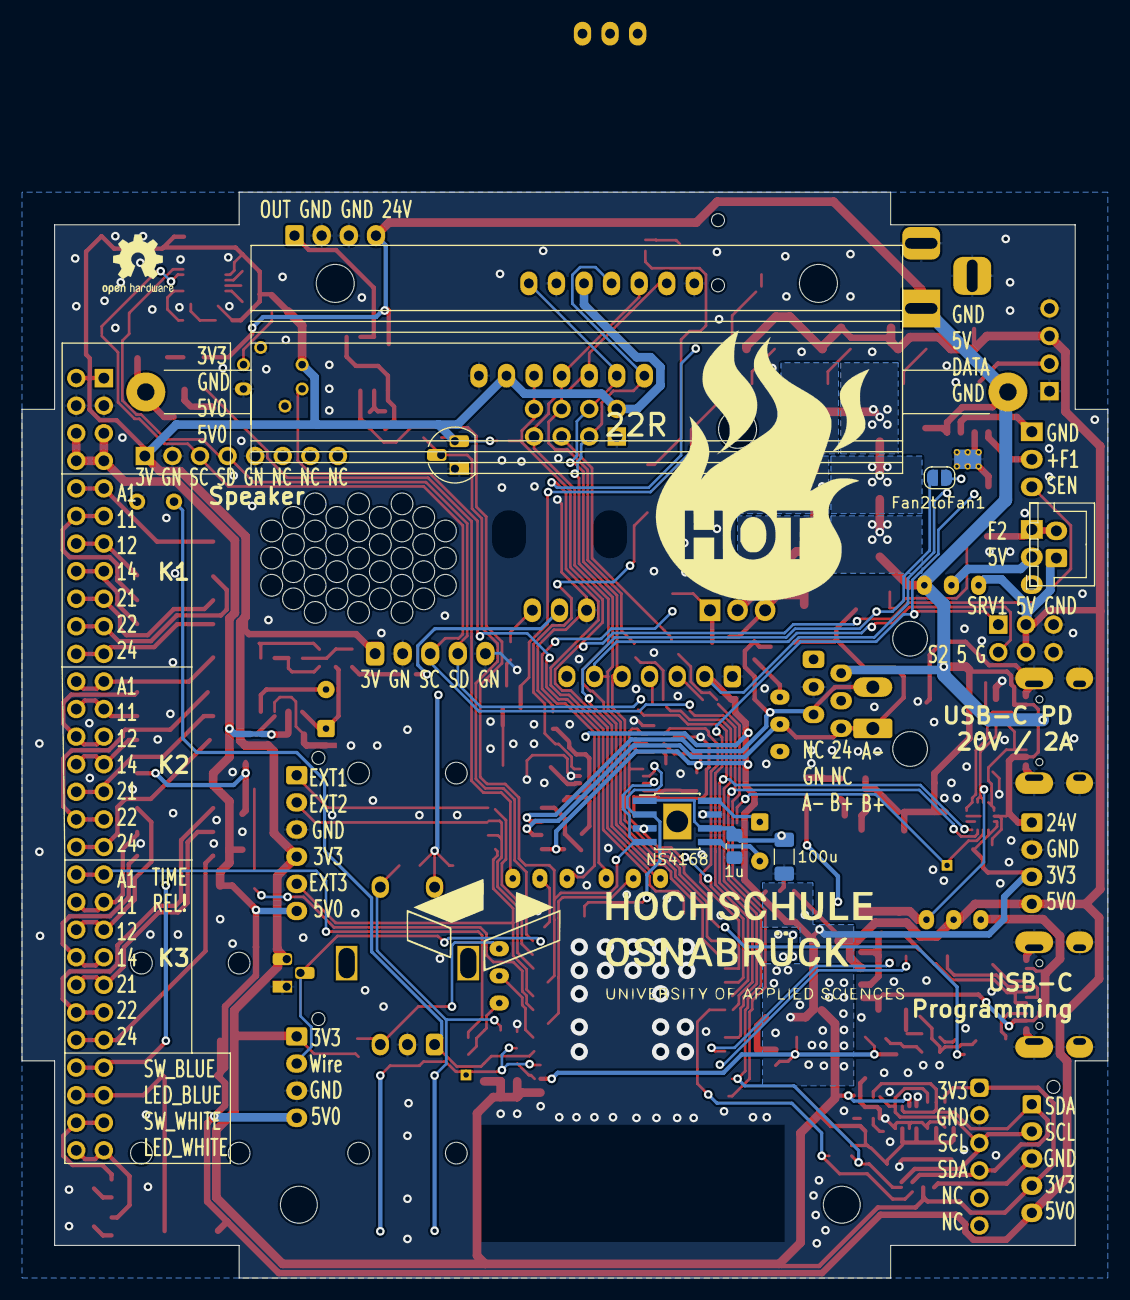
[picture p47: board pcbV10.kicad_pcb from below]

Board: 2 copper layers, 100.0 x 100.0 mm, 221 parts (12 on the bottom side), 144 nets.

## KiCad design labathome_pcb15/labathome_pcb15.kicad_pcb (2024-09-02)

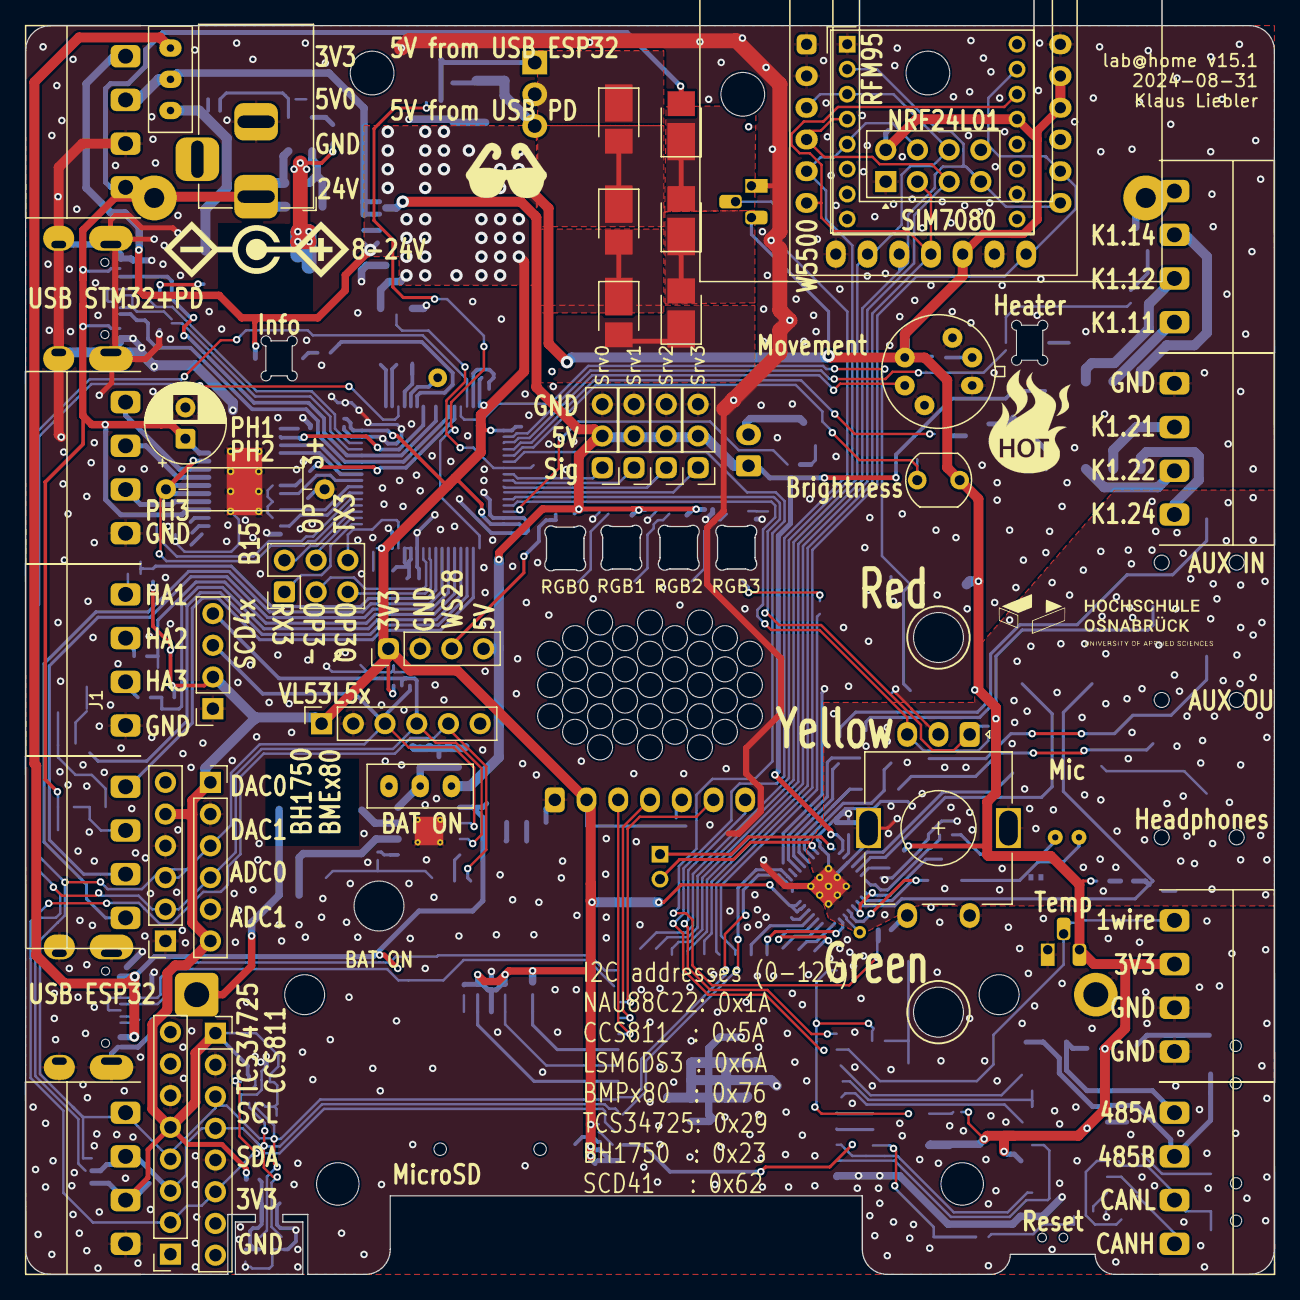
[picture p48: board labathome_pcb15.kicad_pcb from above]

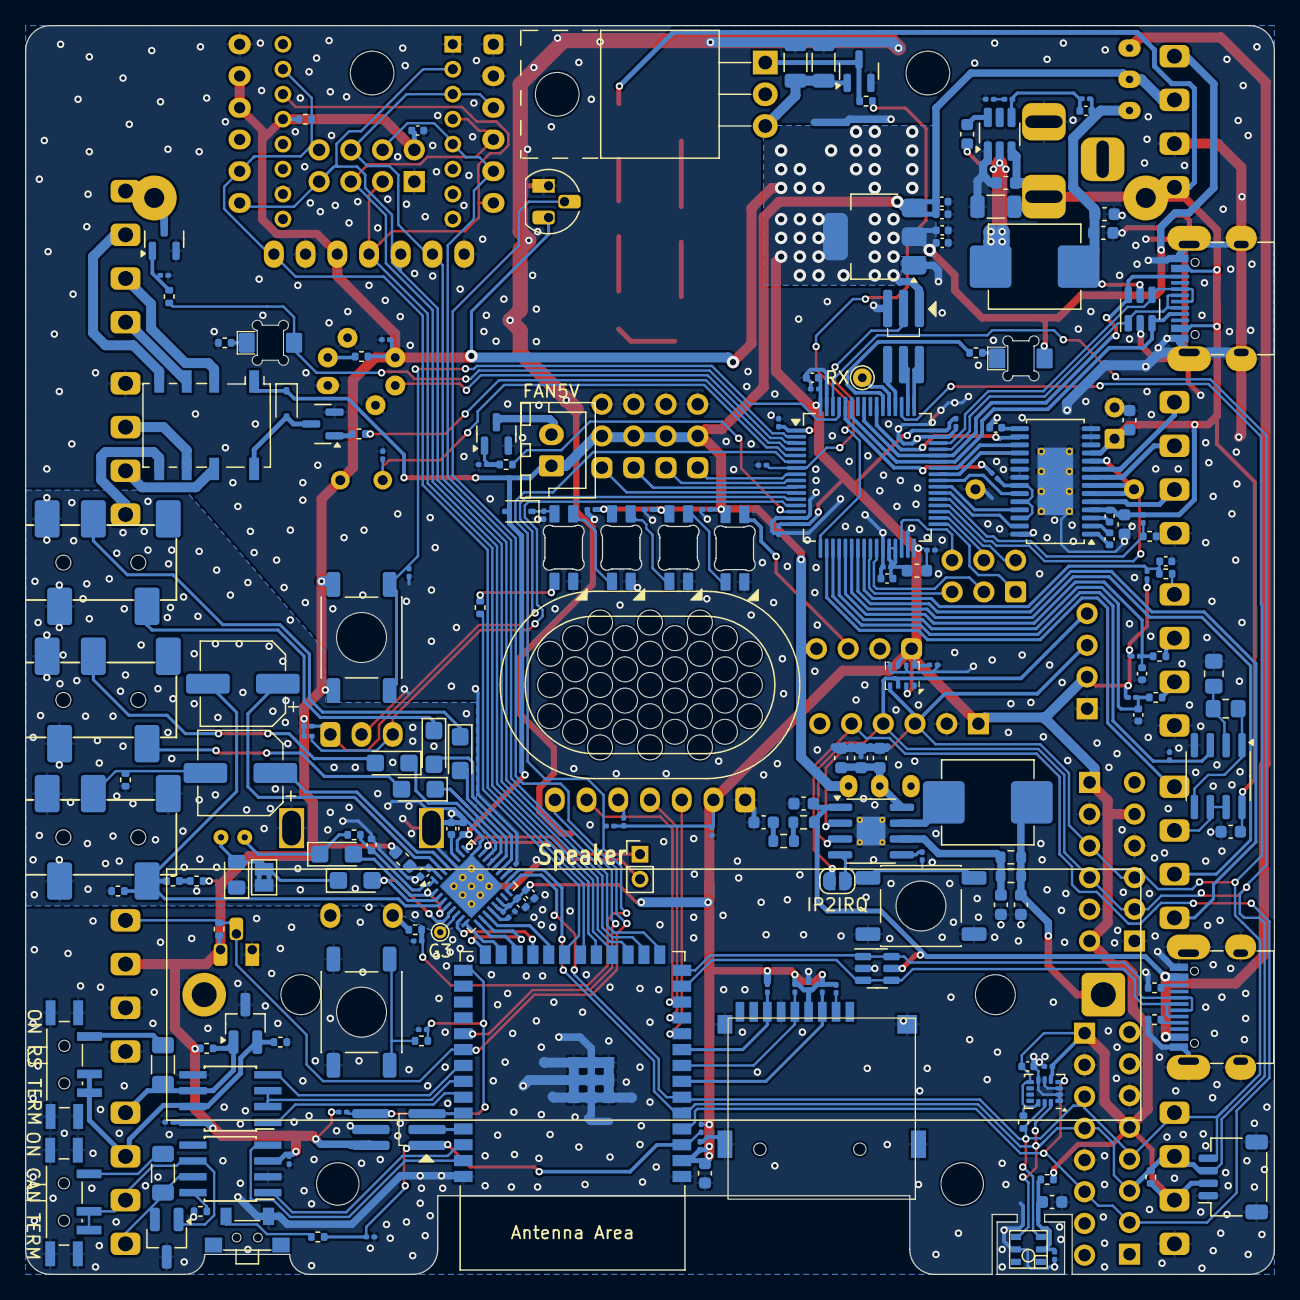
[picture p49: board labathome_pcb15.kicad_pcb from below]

Board: 2 copper layers, 100.0 x 100.0 mm, 242 parts (193 on the bottom side), 183 nets.

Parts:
BT1: 18650; BatteryHolder_MPD_BH-18650-PC2
C1, C4: 10u; C_0603_1608Metric
C2, C3, C5, C11, C25, C26, C27, C32, C33, C34, C35, C40, C45, C46, C47, C48, C49, C50, C53, C54, C57, C58, C60, C65, C66: u1; C_0201_0603Metric
C6, C7, C28, C29, C30, C31, C56, C83, C84: 22u; C_0603_1608Metric
C8, C9, C10: 10p; C_0402_1005Metric
C12, C13, C14, C15, C21, C22, C36, C41, C43: 4u7; C_0402_1005Metric
C16, C17, C20, C23, C24, C62: 1u; CP_EIA-3216-10_Kemet-I
C18, C19: 220u; CP_Elec_6.3x5.4
C37, C42, C44, C59: 1u; C_0402_1005Metric
C38: 10n/35V; C_0402_1005Metric
C39: 100u; CP_Radial_D6.3mm_P2.50mm
C51: u1/16V; C_0402_1005Metric
C52, C63: u1/50V; C_0603_1608Metric
C55: u1; C_0402_1005Metric
C61: 4u7/6V3; C_0402_1005Metric
C64: u1/24V; C_0603_1608Metric
C79: u1/35V; C_0603_1608Metric
C80: 10u/35V; C_1206_3216Metric
C81: u1/16V; C_0603_1608Metric
C82: 56p; C_0402_1005Metric
D2: PSM712; SOT-23_Handsoldering
D3: NUP2105; SOT-23_Handsoldering
D7, D8, D9, D10, D11, D12: WHITE; LED_PLCC_2835_Handsoldering
D13, D20: 1N5819WS; D_SOD-323
D14: HTR ON; LED_1206_3216Metric_ReverseMount
D15: RGB2; SK6812MINI-E_REV
D16: RGB1; SK6812MINI-E_REV
D17: RGB0; SK6812MINI-E_REV
D19: INFO; LED_1206_3216Metric_ReverseMount
D21: RGB3; SK6812MINI-E_REV
DRAWING1: Polarity; barrel_jack_positive_polarity
FB1, FB2: 600R; L_0603_1608Metric
J1: HALL; PhoenixContact_MC_1,5_4-G-3.5_1x04_P3.50mm_Horizontal_small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
J2: I2C; PhoenixContact_MC_1,5_4-G-3.5_1x04_P3.50mm_Horizontal_small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
J3: AUX IN; PJ-327A
J4: SCD4x; PinSocket_1x04_P2.54mm_Vertical
J5: USB_ESP32; USB_C_Receptacle_HRO_TYPE-C-31-M-12_IMPROVED
J6: PROG ESP; PinHeader_2x03_P1.27mm_Vertical_SMD_handsolder
J7: FAN5V; JST_XH_B2B-XH-A_1x02_P2.50mm_Vertical
J8: 3V GN RGB 5V; PinHeader_1x04_P2.54mm_Vertical
J9: Barrel_Jack_Switch; BarrelJack_Horizontal
J10: BMEx80; PinSocket_1x06_P2.54mm_Vertical
J11: QWIIC; JST_SH_SM04B-SRSS-TB_1x04-1MP_P1.00mm_Horizontal
J12: TCS34725; PinSocket_1x08_P2.54mm_Vertical
J13: POWER; USB_C_Receptacle_HRO_TYPE-C-31-M-12_IMPROVED
J14: AUX OUT; PJ-327A
J15: CAN RS 485; PhoenixContact_MC_1,5_4-G-3.5_1x04_P3.50mm_Horizontal_small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
J16: Headphones; PJ-327A
J17: Micro_SD_Card_Det1; microSD push
J18, J24: K1; PhoenixContact_MC_1,5_4-G-3.5_1x04_P3.50mm_Horizontal_small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
J19: BH1750; PinSocket_1x06_P2.54mm_Vertical
J20: CCS811; PinSocket_1x08_P2.54mm_Vertical
J21: GPIO; PhoenixContact_MC_1,5_4-G-3.5_1x04_P3.50mm_Horizontal_small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
J22: Volts; PhoenixContact_MC_1,5_4-G-3.5_1x04_P3.50mm_Horizontal_small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
J23: VL53L5x; PinSocket_1x06_P2.54mm_Vertical
J26: PROG STM; PinHeader_2x03_P1.27mm_Vertical_SMD_handsolder
J27: ADDA; PhoenixContact_MC_1,5_4-G-3.5_1x04_P3.50mm_Horizontal_small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
J28: Brushless; PhoenixContact_MC_1,5_4-G-3.5_1x04_P3.50mm_Horizontal_small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
J30: Srv3; PinHeader_1x03_P2.54mm_Vertical_smallerCourtyard
J31: Srv0; PinHeader_1x03_P2.54mm_Vertical_smallerCourtyard
J32: Srv1; PinHeader_1x03_P2.54mm_Vertical_smallerCourtyard
J33: Srv2; PinHeader_1x03_P2.54mm_Vertical_smallerCourtyard
J34: STM32 EXT; PinHeader_2x03_P2.54mm_Vertical
JP1: Jumper_2_Bridged; SolderJumper-2_P1.3mm_Bridged2Bar_Pad1.0x1.5mm
JP2: IP2IRQ; SolderJumper-2_P1.3mm_Open_RoundedPad1.0x1.5mm
K1: G6K-2; Relay_DPDT_Omron_G6K-2F-Y
L1: 1u; L_0630
L4: 10u; L_0630
LS1: Speaker; PinHeader_1x02_P2.00mm_Vertical
LS2: Speaker; SPEAKER_2415
M1: W5500_mini; W5500-mini
MK1: Mic; Microphone_6mm
NT1: NetTie_2; NetTie-2_SMD_Pad0.5mm
Q1, Q4: BC817; SOT-23
Q2, Q5: IRLML6344; SOT-23
Q3: TIP41; TO-220-3_Horizontal_TabUp
R1, R9, R40, R66, R70: k22; R_0402_1005Metric
R2, R4, R11, R17, R26, R31, R36, R37, R39, R41, R45, R50, R51, R56, R57, R58, R60, R61, R62, R63, R64, R67, R68: 10k; R_0201_0603Metric
R3, R7, R28, R47: 1R; R_0603_1608Metric
R5, R6, R8, R12, R29, R30, R34, R35, R42, R69: 1k; R_0402_1005Metric
R10, R14, R16, R24: 2k2; R_0402_1005Metric
R13, R15: 10R; R_1206_3216Metric
R18, R19: 5k1; R_0402_1005Metric
R20, R46: K12; R_1206_3216Metric_Pad1.30x1.75mm_HandSolder
R21, R43, R44: 4k7; R_0402_1005Metric
R22, R27, R55: 10k; R_0402_1005Metric
R23: 0R; D_0805_2012Metric_Pad1.15x1.40mm_HandSolder
R25, R53, R54: M1; R_0402_1005Metric
R32: GL5516; R_LDR_5.1x4.3mm_P3.4mm_Vertical
R33: 22R; Resistor_100W
R38: r1; R_Axial_DIN0309_L9.0mm_D3.2mm_P12.70mm_Horizontal
R48: 3k3; R_0201_0603Metric
R49: 10k; R_0805_2012Metric_Pad1.20x1.40mm_HandSolder
R52: 22k; R_0805_2012Metric_Pad1.20x1.40mm_HandSolder
R59: M1; R_0201_0603Metric
SW1: Reset; Button_2x4x3,5_handsolder
SW2: ON RS TERM; SW_SPDT_PCM12_handsolder
SW3: ON CAN TERM; SW_SPDT_PCM12_handsolder
SW4: BATT POWER; Switch_SS12D00
SW5: POWER; SW_Push_1P1T_NO_6x6mm_H6.5mm_Reverse
SW6: YELLOW; RotaryEncoder_Alps_EC11E-Switch_Vertical_H20mm
SW7: RED; SW_Push_1P1T_NO_6x6mm_H6.5mm_Reverse
SW8: GREEN; SW_Push_1P1T_NO_6x6mm_H6.5mm_Reverse
SW9: PROG 5V POWER; Switch_SS12D00
TP1: RX; TestPoint_THTPad_D1.5mm_Drill0.7mm
TP6: G3; TestPoint_THTPad_D1.0mm_Drill0.5mm
U1: MAX3485; SOIC-8_3.9x4.9mm_Pitch1.27mm_handsolder
U2: IP5306_I2C; HSOP-8-1EP_3.9x4.9mm_P1.27mm_EP2.3x2.3mm_ThermalVias
U3: DRV8313; HTSSOP-28-1EP_4.4x9.7mm_P0.65mm_EP2.85x5.4mm_ThermalVias
U4: ESP32-S3-WROOM-1
U5: STM32G431R8Tx; LQFP-64_10x10mm_P0.5mm
U6: RFM95W-868S2; HOPERF_RFM9XW_THT
U7: SN65HVD230; SOIC-8_3.9x4.9mm_Pitch1.27mm_handsolder
U8: SRV05-4; SOT-23-6
U9: LSM6DS3; LGA-14_3x2.5mm_P0.5mm_LayoutBorder3x4y
U10: NAU8822; QFN-32-1EP_5x5mm_P0.5mm_EP3.6x3.6mm_ThermalVias
U11: AMS1117; SOT-223-3_TabPin2
U12: AHT20; AHT21
U13, U17: DS18B20; TO-92_HandSolder
U14: BMx280; Bosch_LGA-8_2x2.5mm_P0.65mm_ClockwisePinNumbering
U15: NRF24L01; nRF24L01_Breakout
U16: LM358; SOIC-8_3.9x4.9mm_P1.27mm
U21: IPS_240_240; IPS_240_240_1.3
U22: AM612
U24: SRV05; SOT-23-6
U27: TPS54202DDC; SOT-23-6_Handsoldering
X1: FAN_6024
X3: SIM7080G; SIM7080G_AND_MODULE

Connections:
1wire: J21.4, R42.1, U4.32 (MTCK/GPIO39/CLK_OUT3/SUBSPICS1), U13.2 (DQ), U17.2 (DQ)
24V_SENSE: R68.2, R69.1, U5.37 (PB15)
485_DE: U1.2 (~RE), U1.3 (DE), U4.34 (MTDI/GPIO41/CLK_OUT1)
485_DI: U1.4 (DI), U4.33 (MTDO/GPIO40/CLK_OUT2)
485_RO: U1.1 (RO), U4.35 (MTMS/GPIO42)
+3.3VA: C14.1, FB1.1, U10.31 (VDDA)
+3V3: C2.1, C3.2, C6.1, C11.1, C12.1, C13.1, C26.2, C27.1, C32.1, C33.1, C34.1, C35.1, C36.1, C43.2, C44.1, C50.1, C54.2, C55.2, C58.2, C59.1, C60.2, C65.1, C66.1, D19.2 (A), FB1.2, FB2.2, J2.3, J4.2, J6.2, J8.1, J10.1, J10.6, J11.2, J12.5, J17.4 (VDD), J19.5, J20.1, J21.3, J22.1, J23.1, J26.1, M1.10 (3V3), M1.11 (3V3), R2.2, R8.1, R9.1, R17.1, R22.1, R32.1, R36.2, R37.1, R41.1, R42.2, R43.2, R44.2, R51.1, R53.1, R54.1, R56.1, R57.1, R58.1, R61.1, R62.1, R64.1, R67.1, SW7.1, U1.8 (VCC), U4.2 (3V3), U5.1 (VBAT), U5.16 (VDD), U5.32 (VDD), U5.48 (VDD), U5.64 (VDD), U6.13 (3.3V), U7.3 (VCC), U9.5 (VDDIO), U9.8 (VDD), U9.12 (CS), U10.13 (VDDC), U10.14 (VDDB), U11.2 (VO), U13.3 (V_{DD}), U14.2 (CSB), U14.6 (VDDIO), U14.8 (VDD), U15.2 (VCC), U17.3 (V_{DD}), U21.2 (VCC), U22.4 (VDD), X3.5 (V-VCC)
+3V8: BT1.1 (+), C29.1, L1.2, R7.1, R28.1
+5P: C4.1, J5.A4 (VBUS), J5.A9 (VBUS), J5.B4 (VBUS), J5.B9 (VBUS), R47.1, SW9.3 (C), U2.1 (VIN), U8.5 (VP)
+5V: C15.1, C41.2, C42.1, C46.2, C47.2, C48.2, D13.1 (K), D15.1 (VDD), D16.1 (VDD), D17.1 (VDD), D20.2 (A), J7.1, J8.4, J22.2, J30.2, J31.2, J32.2, J33.2, K1.1, SW4.1 (A), SW9.2 (B), U10.26 (VDDSPK), U11.3 (VI)
+24V: C39.1, C51.2, C52.2, C63.1, C64.2, C79.2, C80.2, D7.2 (A), J9.2, J13.A4 (VBUS), J13.A9 (VBUS), J13.B4 (VBUS), J13.B9 (VBUS), J22.4, R33.1, R68.1, U3.4 (VM), U3.11 (VM), U16.8 (V+), U27.3 (VIN)
/USB+: J5.A6 (D+), J5.B6 (D+), U4.14 (GPIO20/U1CTS/ADC2_CH9/CLK_OUT1/USB_D+), U8.1 (IO1), U8.6 (IO4)
/USB-: J5.A7 (D-), J5.B7 (D-), U4.13 (GPIO19/U1RTS/ADC2_CH8/CLK_OUT2/USB_D-), U8.3 (IO2), U8.4 (IO3)
/actors/D9_COOL: D12.1 (K), Q3.2 (C)
/actors/D10_COOL: D9.1 (K), D10.2 (A)
/actors/D11_COOL: D10.1 (K), D11.2 (A)
/actors/D12_COOL: D8.1 (K), D9.2 (A)
/actors/D13_COOL: D11.1 (K), D12.2 (A)
/actors/D14_COOL: D7.1 (K), D8.2 (A)
/audioamplifier/JACK_DETECT: C18.2, J16.T, R25.2, R27.1, U10.3 (LLIN/GPIO2)
/psu/5Vx: C82.2, C83.1, C84.1, L4.1, R59.1, SW9.1 (A), U24.5 (VP)
/psu/BOOT: C81.1, U27.6 (BOOT)
/psu/FB: C82.1, R59.2, R60.2, U27.4 (FB)
/psu/SW: C81.2, L4.2, U27.2 (SW)
ADC0: J27.3, U5.22 (PC4)
ADC1: J27.4, U5.23 (PC5)
BL_DRV1: U3.27 (IN1), U5.38 (PC6)
BL_DRV2: U3.25 (IN2), U5.39 (PC7)
BL_DRV3: U3.23 (IN3), U5.40 (PC8)
BL_ENABLE: R63.2, U3.22 (EN3), U3.24 (EN2), U3.26 (EN1)
BL_ENABLEx: R63.1, U5.60 (PB7)
BL_FAULT: U3.18 (nFAULT), U5.41 (PC9)
BL_HALL1: C8.1, R16.2, R17.2, U5.24 (PB0)
BL_HALL2: C9.1, R14.2, R51.2, U5.21 (PA7)
BL_HALL3: C10.1, R10.2, R64.2, U5.20 (PA6)
BL_ISENSE: R38.1, U3.6 (PGND1), U3.7 (PGND2), U3.10 (PGND3), U5.36 (PB14)
BL_RESET: U3.16 (nRESET), U5.55 (PD2)
BL_SLEEP: U3.17 (nSLEEP), U5.42 (PA8)
BRIGHTNESS: R11.1, R32.2, U5.5 (PF0)
BTN_GRN: C53.2, J6.6, R40.1, R41.2, U4.27 (GPIO0/BOOT)
BTN_RED: R39.1, SW7.2, U5.61 (PB8)
BTN_YEL: C40.2, R66.2, R67.2, U5.6 (PF1)
CANH: D3.2 (A2), J15.1, R46.2, U7.7 (CANH)
CANL: D3.1 (A1), J15.2, SW3.2 (B), SW3.3 (C), U7.6 (CANL)
CAN_RX: U4.39 (GPIO1/TOUCH1/ADC1_CH0), U7.4 (R)
CAN_TX: U4.38 (GPIO2/TOUCH2/ADC1_CH1), U7.1 (D)
DAC0: J27.1, U5.18 (PA4)
DAC1: R50.2, U5.19 (PA5), U16.3 (+)
DAC1x: J27.2, U16.6 (-), U16.7
EXT_CLK: M1.4 (SCLK), U4.18 (GPIO10/TOUCH10/ADC1_CH9/FSPICS0/FSPIIO4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), U6.4 (SCK), U15.5 (SCK)
EXT_CS: M1.5 (~CS[PU]), U4.15 (GPIO3/TOUCH3/ADC1_CH2), U6.5 (NSS), U15.4 (~CSN)
EXT_IO1: M1.6 (~INT[PU]), U4.19 (GPIO11/TOUCH11/ADC2_CH0/FSPID/FSPIIO5/S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), U6.14 (DIO0), U15.3 (CE), X3.4 (K-PWRKEY)
EXT_IO2: M1.8 (~RST[PU]), R22.2, U4.20 (GPIO12/TOUCH12/ADC2_CH1/FSPICLK/FSPIIO6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), U6.15 (DIO1), U15.8 (IRQ), X3.7 (S-SLEEP)
EXT_MISO: M1.7 (MISO), U4.17 (GPIO9/TOUCH9/ADC1_CH8/FSPIHD/SUBSPIHD), U6.2 (MISO), U15.7 (MISO), X3.3 (T-TX)
EXT_MOSI: M1.3 (MOSI), U4.16 (GPIO46), U6.3 (MOSI), U15.6 (MOSI), X3.2 (R-RXD)
FAN_DRIVE: R35.2, U5.14 (PA2)
GND: BT1.2 (-), C1.2, C2.2, C3.1, C4.2, C5.2, C6.2, C7.2, C8.2, C9.2, C10.2, C11.2, C12.2, C13.2, C25.2, C26.1, C27.2, C28.1, C29.2, C30.1, C31.1, C32.2, C33.2, C34.2, C35.2, C36.2, C37.2, C39.2, C40.1, C41.1, C42.2, C43.1, C44.2, C45.1, C46.1, C47.1, C48.1, C49.2, C50.2, C52.1, C53.1, C54.1, C55.1, C56.2, C57.1, C58.1, C59.2, C60.1, C61.2, C63.2, C64.1, C65.2, C66.2, C79.1, C80.1, C83.2, C84.2, D2.3 (A), D3.3 (common), D15.3 (GND), D16.3 (GND), D17.3 (GND), D21.3 (GND), J1.4, J2.4, J4.1, J5.A1 (GND), J5.A12 (GND), J5.B1 (GND), J5.B12 (GND), J5.S1 (SHIELD), J6.4, J8.2, J9.1, J10.2, J10.5, J11.1, J11.MP (MountPin), J12.6, J13.A1 (GND), J13.A12 (GND), J13.B1 (GND), J13.B12 (GND), J13.S1 (SHIELD), J17.6 (VSS), J17.10 (SHIELD), J18.4, J19.1, J19.4, J20.2, J20.5, J21.1, J21.2, J22.3, J23.2, J26.5, J28.4, J30.3, J31.3, J32.3, J33.3, M1.1 (GND), M1.2 (GND), M1.12 (GND), NT1.1, Q1.2 (E), Q2.2 (S), Q4.2 (E), Q5.2 (S), R5.2, R6.1, R11.2, R13.2, R15.2, R18.2, R19.2, R21.2, R26.2, R31.1, R38.2, R39.2, R45.1, R48.1, R49.1, R50.1, R69.2, SW1.1, SW2.CASE, SW3.CASE, SW5.1, SW6.C, SW6.S2, SW8.1, U1.5 (GND), U2.9, U3.12 (COMPP), U3.13 (COMPN), U3.14 (GND), U3.20 (GND), U3.21 (NC_GND), U3.28 (GND), U3.29 (EP_GND), U4.1 (GND), U4.40 (GND), U4.41 (GND), U5.15 (VSS), U5.27 (VSSA), U5.31 (VSS), U5.47 (VSS), U5.63 (VSS), U6.1 (GND), U6.8 (GND), U6.10 (GND), U7.2 (GND), U8.2 (VN), U9.1 (SDO/SA0), U9.2 (SDX), U9.3 (SCX), U9.6 (GND), U9.7 (GND), U10.12 (VSSD), U11.1 (GND), U12.5 (GND), U13.1 (GND), U14.1 (GND), U14.5 (SDO), U14.7 (GND), U15.1 (GND), U16.4 (V-), U17.1 (GND), U21.1 (GND), U22.1 (SENS), U22.3 (VSS_GND), U22.6 (TIME), U24.2 (VN), U27.1 (GND), X3.1 (G-GND), X3.6 (G-GND)
GNDA: C14.2, C15.2, C21.2, C22.2, J3.S, J14.S, J16.S, J16.TN, JP1.1 (A), NT1.2, R23.1, R27.2, R55.2, SW6.MP, U10.24 (VSSSPK), U10.28 (VSSA), U10.33 (EXPOSED_PAD)
HEATER: D14.2 (A), R30.2, U5.2 (PC13)
HEATER_SW: J24.4, Q2.3 (D), R33.2
I2C_IRQ: J12.2, J20.6, J23.5, JP2.1 (A), U4.4 (GPIO4/TOUCH4/ADC1_CH3), U9.4 (INT1)
I2S_ADC: U4.24 (GPIO47/SPICLK_P/SUBSPICLK_P_DIFF), U10.9 (ADCOUT)
I2S_BCLK: U4.25 (GPIO48/SPICLK_N/SUBSPICLK_N_DIFF), U10.8 (BCLK)
I2S_DAC: U4.26 (GPIO45), U10.10 (DACIN)
I2S_FS: U4.23 (GPIO21), U10.7 (FS)
I2S_MCLK: U4.22 (GPIO14/TOUCH14/ADC2_CH3/FSPIWP/FSPIDQS/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), U10.11 (MCLK)
K1_11: J24.1, K1.3
K1_12: J24.2, K1.2
K1_14: J24.3, K1.4
K1_21: J18.3, K1.6
K1_22: J18.2, K1.7
K1_24: J18.1, K1.5
LCD_BACKLIGHT: U4.31 (GPIO38/FSPIWP/SUBSPIWP), U21.7 (BLK)
LCD_CLK: U4.10 (GPIO17/U1TXD/ADC2_CH6), U21.3 (SCL)
LCD_DAT: U4.11 (GPIO18/U1RXD/ADC2_CH7/CLK_OUT3), U21.4 (SDA)
LCD_DC: U4.12 (GPIO8/TOUCH8/ADC1_CH7/SUBSPICS1), U21.6 (DVC)
LED_INFO: R34.1, U5.54 (PC12)
LED_RGB: R70.2, U4.21 (GPIO13/TOUCH13/ADC2_CH2/FSPIQ/FSPIIO7/S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)
LED_WHITE_P: R12.2, U5.17 (PA3)
MOVE: U5.3 (PC14), U22.5 (OUT)
unnamed: C1.1, R3.2
unnamed: C16.2, J14.T
unnamed: C17.2, J14.R
unnamed: C19.2, J16.R, R55.1
unnamed: C24.1, J3.R
unnamed: C62.1, J3.T
unnamed: D13.2 (A), K1.8, Q4.3 (C)
unnamed: D14.1 (K), R6.2
unnamed: D15.4 (DIN), D21.2 (DOUT)
unnamed: D15.2 (DOUT), D16.4 (DIN)
unnamed: D16.2 (DOUT), D17.4 (DIN)
unnamed: D17.2 (DOUT), J8.3
unnamed: D19.1 (K), R34.2
unnamed: C45.2, D20.1 (K), D21.1 (VDD)
unnamed: D21.4 (DIN), R70.1
unnamed: J1.1, R16.1
unnamed: J1.2, R14.1
unnamed: J1.3, R10.1
unnamed: J5.A5 (CC1), R18.1
unnamed: J5.B5 (CC2), R19.1
unnamed: J7.2, Q5.3 (D)
unnamed: J17.2 (DAT3/CD), R61.2
unnamed: J28.1, U3.9 (OUT3)
unnamed: J28.2, U3.8 (OUT2)
unnamed: J28.3, U3.5 (OUT1)
unnamed: C20.1, JP1.2 (B), MK1.1 (-), R23.2
unnamed: JP2.2 (B), U2.4 (IRQ)
unnamed: C23.1, MK1.2 (+), R24.2
unnamed: Q1.1 (B), Q3.3 (E), R13.1, R15.1
unnamed: Q1.3 (C), Q3.1 (B), R12.1
unnamed: Q2.1 (G), R30.1, R31.2
unnamed: Q4.1 (B), R29.1
unnamed: Q5.1 (G), R35.1, R45.2
unnamed: R1.1, SW1.2
unnamed: R3.1, R47.2
unnamed: R4.2, SW5.2
unnamed: R25.1, R54.2
unnamed: R40.2, SW8.2
unnamed: R48.2, R60.1
unnamed: R66.1, SW6.S1
unnamed: R20.2, SW2.1 (A)
unnamed: R46.1, SW3.1 (A)
unnamed: C28.2, C30.2, C31.2, SW4.2 (B), U2.8 (VOUT)
unnamed: C7.1, R7.2, R28.2, U2.6 (BAT)
unnamed: R4.1, U2.5 (KEY)
unnamed: L1.1, U2.7 (SW)
unnamed: C38.2, U3.2 (CPH)
unnamed: C38.1, U3.1 (CPL)
unnamed: C61.1, U3.15 (V3P3)
unnamed: C51.1, U3.3 (VCP)
unnamed: C37.1, C49.1, FB2.1, U5.28 (VREF+), U5.29 (VDDA)
unnamed: R21.1, U7.8 (Rs)
unnamed: C16.1, U10.21 (AUXOUT1)
unnamed: C17.1, U10.22 (AUXOUT2)
unnamed: C62.2, U10.19 (LAUXIN)
unnamed: C18.1, U10.30 (LHP)
unnamed: C20.2, U10.2 (LMICN), U10.5 (RMICN)
unnamed: C23.2, U10.1 (LMICP), U10.4 (RMICP)
unnamed: LS1.1, U10.25 (LSPKOUT)
unnamed: C22.1, R24.1, U10.32 (MICBIAS)
unnamed: R26.1, U10.18 (MODE)
unnamed: C24.2, U10.20 (RAUXIN)
unnamed: C19.1, U10.29 (RHP)
unnamed: TP6.1, U10.6 (RLIN/GPIO3)
unnamed: LS1.2, U10.23 (RSPKOUT)
unnamed: C21.1, U10.27 (VREF)
unnamed: C56.1, C57.2, R9.2, U12.2 (VDD)
unnamed: R49.2, R52.2, U16.2 (-)
unnamed: R52.1, U16.1, U16.5 (+)
unnamed: R62.2, U21.5 (RES)
unnamed: R53.2, U22.2 (OEN)
OPAMP3+: J34.2, U5.35 (PB13)
OPAMP3-: J34.3, U5.26 (PB2)
OPAMP3Q: J34.5, U5.25 (PB1)
PB12: J34.4, U5.34 (PB12)
PROG_EN: C5.1, J6.1, R1.2, R2.1, U4.3 (EN)
PROG_RX: J6.5, U4.36 (U0RXD/GPIO44/CLK_OUT2)
PROG_TX: J6.3, U4.37 (U0TXD/GPIO43/CLK_OUT1)
ROT_A: R36.1, SW6.A, U5.12 (PA0)
ROT_B: R37.2, SW6.B, U5.13 (PA1)
RS485A: D2.1 (K), J15.4, R8.2, R20.1, U1.6 (A)
RS485B: D2.2 (K), J15.3, R5.1, SW2.2 (B), SW2.3 (C), U1.7 (B)
Relais: R29.2, U5.4 (PC15)
SCL: J2.1, J4.3, J10.3, J11.4, J12.4, J19.3, J20.3, J23.3, R44.1, U2.2 (SCL), U4.6 (GPIO6/TOUCH6/ADC1_CH5), U5.51 (PA15), U9.13 (SCL), U10.16 (SCLK), U12.3 (SCL), U14.4 (SCK)
SDA: J2.2, J4.4, J10.4, J11.3, J12.3, J19.2, J20.4, J23.4, R43.1, U2.3 (SDA), U4.5 (GPIO5/TOUCH5/ADC1_CH4), U5.62 (PB9), U9.14 (SDA), U10.17 (SDIO), U12.4 (SDA), U14.3 (SDI)
STM32_RESET: C25.1, J26.3, U5.7 (PG10)
SWCLK: J26.4, U5.50 (PA14)
SWDIO: J26.2, U5.49 (PA13)
Servo0: J31.1, U5.8 (PC0)
Servo1: J32.1, U5.9 (PC1)
Servo2: J33.1, U5.10 (PC2)
Servo3: J30.1, U5.11 (PC3)
UART3_RX: J34.1, U5.33 (PB11)
UART3_TX: J34.6, U5.30 (PB10)
UART4_RX: TP1.1, U5.53 (PC11)
UART4_TX: J26.6, U5.52 (PC10)
USBPD_CC1: J13.A5 (CC1), U5.43 (PA9), U5.59 (PB6), U24.3 (IO2)
USBPD_CC2: J13.B5 (CC2), U5.44 (PA10), U5.57 (PB4), U24.6 (IO4)
USBPD_D+: J13.A6 (D+), J13.B6 (D+), U5.46 (PA12), U24.4 (IO3)
USBPD_D-: J13.A7 (D-), J13.B7 (D-), U5.45 (PA11), U24.1 (IO1)
uSD_CLK: J17.5 (CLK), R57.2, U4.8 (GPIO15/U0RTS/ADC2_CH4/XTAL_32K_P)
uSD_CMD: J17.3 (CMD), R56.2, U4.7 (GPIO7/TOUCH7/ADC1_CH6)
uSD_D0: J17.7 (DAT0), R58.2, U4.9 (GPIO16/U0CTS/ADC2_CH5/XTAL_32K_NH5)

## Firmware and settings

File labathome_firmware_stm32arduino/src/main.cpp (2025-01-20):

#include <cstdio>
#include "Arduino.h"
#include <Wire.h>
#include "USBPowerDelivery.h"
#include <SimpleFOC.h>

#include "log.h"
#include <common.hh>
#include <gpioG4.hh>
#include <single_led.hh>
#include "encoder.hh"
#include "errorcheck.hh"
#include "stm32_esp32_communication.hh"
#include "errormanager.hh"

#if defined(ARDUINO_LABATHOME_15_3)
  // #include <TMCStepper.h>
  #include <TMC2209.h>
  #include <HardwareSerial.h>
  #include "busservo.hh"
#endif

#include "hal.hh"

constexpr uint8_t DRIVER_ADDRESS{0b00};
constexpr float R_SENSE{0.11f};

float brushless_motor_velocity{0.0};
constexpr int POLE_PAIRS{7};
BLDCMotor bldcmotor = BLDCMotor(POLE_PAIRS);
BLDCDriver3PWM bldcdriver = BLDCDriver3PWM(PIN::BL_DRV1, PIN::BL_DRV2, PIN::BL_DRV3, PIN::BL_ENABLE);

constexpr time_t TIMEOUT_FOR_FAILSAFE{3000};
bool alreadySetToFailsafe{false};
bool gotDataInfoAlreadyPrinted{false};

// Time related
uint32_t timeToPutActorsInFailsafe{TIMEOUT_FOR_FAILSAFE};

ErrorManager<8, uint32_t> errMan;

SINGLE_LED::M *led{nullptr};
HardwareTimer *TIM_BL_DRV{nullptr}; // TIM1 for Brushless
constexpr uint32_t BL_DRV_PH1_CH = 1;
constexpr uint32_t BL_DRV_PH2_CH = 2;
constexpr uint32_t BL_DRV_PH3_CH = 3;
ROTARY_ENCODER::M encoder;
constexpr uint32_t ROTENC_A_CH = 1;
constexpr uint32_t ROTENC_B_CH = 2;
HardwareTimer *TIM_HALL{nullptr}; // TIM3 for Hall Sensors, ch 2,3,4
constexpr uint32_t HALL_PH1_CH_CH = 4;
constexpr uint32_t HALL_PH2_CH_CH = 3;
constexpr uint32_t HALL_PH3_CH_CH = 2;


#ifdef ARDUINO_LABATHOME_15_0
HardwareTimer *TIM_LED_WHITE{nullptr}; // TIM4 for Power LED, ch 4
constexpr uint32_t LED_WHITE_CH = 4;
HardwareTimer *TIM_SERVO_0_1{nullptr}; // TIM15 for Servo0+1, ch1,2
constexpr uint32_t SERVO0_CH = 1;
constexpr uint32_t SERVO1_CH = 2;
HardwareTimer *TIM_SERVO_2{nullptr}; // TIM16 for Servo2, ch1
constexpr uint32_t SERVO2_CH = 1;
HardwareTimer *TIM_FAN{nullptr}; // TIM17 for Fan, ch1
constexpr uint32_t FAN_CH = 1;


#elif defined(ARDUINO_LABATHOME_15_1)
HardwareTimer *TIM_SERVO{nullptr}; // TIM1
constexpr uint32_t SERVO0_CH = 1;
constexpr uint32_t SERVO1_CH = 2;
constexpr uint32_t SERVO2_CH = 3;
constexpr uint32_t SERVO3_CH = 4;
HardwareTimer *TIM_FAN_LED_WHITE{nullptr}; // TIM15
constexpr uint32_t FAN_CH = 1;
constexpr uint32_t LED_WHITE_CH = 2;
OPAMP_HandleTypeDef hopamp2;
OPAMP_HandleTypeDef hopamp3;


#elif defined(ARDUINO_LABATHOME_15_2) 
HardwareTimer *TIM_SERVO{nullptr}; // TIM1
constexpr uint32_t SERVO0_CH = 1;
constexpr uint32_t SERVO1_CH = 2;
constexpr uint32_t SERVO2_CH = 3;
constexpr uint32_t SERVO3_CH = 4;
HardwareTimer *TIM_FAN_LED_WHITE{nullptr}; // TIM15
constexpr uint32_t LED_WHITE_CH = 1;
constexpr uint32_t FAN_CH = 2;
OPAMP_HandleTypeDef hopamp2;
OPAMP_HandleTypeDef hopamp3;


#elif defined(ARDUINO_LABATHOME_15_3)
HardwareTimer *TIM_SERVO{nullptr}; // TIM1
constexpr uint32_t SERVO0_CH = 1;
constexpr uint32_t SERVO1_CH = 2;
constexpr uint32_t SERVO2_CH = 3;
constexpr uint32_t SERVO3_CH = 4;
HardwareTimer *TIM_FAN_LED_WHITE{nullptr}; // TIM15
constexpr uint32_t LED_WHITE_CH = 1;
constexpr uint32_t FAN_CH = 2;
OPAMP_HandleTypeDef hopamp2;
OPAMP_HandleTypeDef hopamp3;
HardwareSerial StepperSerial(PIN::UART3_RX, PIN::UART3_TX);
//Important: Define TX-Pin in the "const PinMap PinMap_UART_TX[]"-structure as OpenDrain
HardwareSerial ServoBusSerial(PIN::ADC1_U1R, PIN::ADC0_U1T);
// TMC2209Stepper stepperdriver(PIN::UART3_RX, PIN::UART3_TX, R_SENSE, DRIVER_ADDRESS);
HardwareSerial & stepper_serial_stream = StepperSerial;
TMC2209 stepperdriver;
//SMS_STS servoBus;
ServoBus<true, GPIO::Pin::C4> servoBus(&ServoBusSerial);


#else
#error "No known board defined"
#endif


SINGLE_LED::BlinkPattern WAITING_FOR_CONNECTION(500, 500);
SINGLE_LED::BlinkPattern UNDER_CONTROL_FROM_MASTER(100, 900);
SINGLE_LED::BlinkPattern PROBLEM(100, 100);

void SetPhysicalOutputs();
uint8_t CollectBitInputs();

uint32_t receivedEvents{0};
uint32_t requestEvents{0};
E2S_t e2s_buffer;
S2E_t s2e_buffer;

// I2C callbacks

extern "C" void HAL_I2C_SlaveTxCpltCallback(I2C_HandleTypeDef *hi2c)
{
  HAL_I2C_EnableListen_IT(hi2c);
}

extern "C" void HAL_I2C_SlaveRxCpltCallback(I2C_HandleTypeDef *hi2c)
{
  SetPhysicalOutputs();
  timeToPutActorsInFailsafe = millis() + 3000;
  ClearBitIdx(s2e_buffer.Status, 2);
  // HAL_I2C_EnableListen_IT(hi2c);
}

extern "C" void HAL_I2C_AddrCallback(I2C_HandleTypeDef *hi2c, uint8_t TransferDirection, uint16_t AddrMatchCode)
{

  UNUSED(AddrMatchCode);
  if (TransferDirection == I2C_DIRECTION_RECEIVE) // TransferDirection is master perspective
  {
    requestEvents++;
    HAL_ERROR_CHECK(HAL_I2C_Slave_Seq_Transmit_IT(hi2c, (uint8_t *)&s2e_buffer, sizeof(s2e_buffer), I2C_LAST_FRAME));
    // HAL_ERROR_CHECK(HAL_I2C_Slave_Seq_Transmit_IT(hi2c, test_buf, 12, I2C_LAST_FRAME));
  }
  else
  {
    receivedEvents++;
    HAL_ERROR_CHECK(HAL_I2C_Slave_Seq_Receive_IT(hi2c, (uint8_t *)&e2s_buffer, sizeof(e2s_buffer), I2C_LAST_FRAME));
  }
  timeToPutActorsInFailsafe = millis() + TIMEOUT_FOR_FAILSAFE;
}

extern "C" void HAL_I2C_ListenCpltCallback(I2C_HandleTypeDef *hi2c)
{
  HAL_I2C_EnableListen_IT(hi2c);
}

extern "C" void HAL_I2C_ErrorCallback(I2C_HandleTypeDef *hi2c)
{

  uint32_t error_code = HAL_I2C_GetError(hi2c);

  SetPhysicalOutputs();
  HAL_I2C_EnableListen_IT(hi2c);
}

namespace USB_PD
{
  void requestVoltage()
  {
    // check if 12V is supported
    for (int i = 0; i < PowerSink.numSourceCapabilities; i += 1)
    {
      if (PowerSink.sourceCapabilities[i].minVoltage <= 12000 && PowerSink.sourceCapabilities[i].maxVoltage >= 12000)
      {
        PowerSink.requestPower(12000);
        return;
      }
    }

    // check if 15V is supported
    for (int i = 0; i < PowerSink.numSourceCapabilities; i += 1)
    {
      if (PowerSink.sourceCapabilities[i].minVoltage <= 15000 && PowerSink.sourceCapabilities[i].maxVoltage >= 15000)
      {
        PowerSink.requestPower(15000);
        return;
      }
    }
    log_warn("Neither 12V nor 15V is supported");
  }

  void handleUsbPdEvent(PDSinkEventType eventType)
  {

    if (eventType == PDSinkEventType::sourceCapabilitiesChanged)
    {
      // source capabilities have changed
      if (PowerSink.isConnected())
      {
        log_info("PD supply is connected");
        for (int i = 0; i < PowerSink.numSourceCapabilities; i += 1)
        {
          log_info("minVoltage: %d maxVoltage:%d current:%d\n", PowerSink.sourceCapabilities[i].minVoltage, PowerSink.sourceCapabilities[i].maxVoltage, PowerSink.sourceCapabilities[i].maxCurrent);
        }
        requestVoltage();
      }
      else
      {
        // no supply or no USB PD capable supply is connected
        PowerSink.requestPower(5000); // reset to 5V
      }
    }
    else if (eventType == PDSinkEventType::voltageChanged)
    {
      // voltage has changed
      if (PowerSink.activeVoltage != 0)
      {
        log_info("Voltage: %d mV @ %d mA (max)", PowerSink.activeVoltage, PowerSink.activeCurrent);
      }
      else
      {
        log_info("Disconnected");
      }
    }
    else if (eventType == PDSinkEventType::powerRejected)
    {
      // rare case: power supply rejected requested power
      log_info("Power request rejected");
      log_info("Voltage: %d mV @ %d mA (max)", PowerSink.activeVoltage, PowerSink.activeCurrent);
    }
  }
}

unsigned int degree2us(unsigned int degrees)
{
  return 1000 + degrees * 150 / 27;
}

void SetServoAngle(uint8_t servo_0_1_2_3_4_5, uint8_t angle_0_180)
{
  if (angle_0_180 > 180)
    angle_0_180 = 180;
  uint32_t us = degree2us(angle_0_180);
  // log_info("Set Servo %d to %lu us", servo_0_1_2_3, us);
#ifdef ARDUINO_LABATHOME_15_0
  switch (servo_0_1_2_3_4_5)
  {
  case 0:
    TIM_SERVO_0_1->setCaptureCompare(SERVO0_CH, us, MICROSEC_COMPARE_FORMAT);
    break;
  case 1:
    TIM_SERVO_0_1->setCaptureCompare(SERVO1_CH, us, MICROSEC_COMPARE_FORMAT);
    break;
  case 2:
    TIM_SERVO_2->setCaptureCompare(SERVO2_CH, us, MICROSEC_COMPARE_FORMAT);
    break;
  default:
    break;
  }
#elif defined(ARDUINO_LABATHOME_15_1)
  if (servo_0_1_2_3_4_5 > 3)
    return;
  TIM_SERVO->setCaptureCompare(servo_0_1_2_3_4_5 + 1, us, MICROSEC_COMPARE_FORMAT);
#elif defined(ARDUINO_LABATHOME_15_2)
  if (servo_0_1_2_3_4_5 < 4)
  {
    TIM_SERVO->setCaptureCompare(servo_0_1_2_3_4_5 + 1, us, MICROSEC_COMPARE_FORMAT);
  }
#endif
}

void SetFanSpeed(uint8_t power_0_100)
{
  if (power_0_100 > 100)
  {
    power_0_100 = 100;
  }
#ifdef ARDUINO_LABATHOME_15_0
  TIM_FAN->setCaptureCompare(FAN_CH, power_0_100, PERCENT_COMPARE_FORMAT);
#elif defined(ARDUINO_LABATHOME_15_1) || defined(ARDUINO_LABATHOME_15_2)
  TIM_FAN_LED_WHITE->setCaptureCompare(FAN_CH, power_0_100, PERCENT_COMPARE_FORMAT);
#endif
}

void SetLedPowerPower(uint8_t power_0_100)
{
  if (power_0_100 > 100)
  {
    power_0_100 = 100;
  }
#ifdef ARDUINO_LABATHOME_15_0
  TIM_LED_WHITE->setCaptureCompare(LED_WHITE_CH, power_0_100, PERCENT_COMPARE_FORMAT);
#elif defined(ARDUINO_LABATHOME_15_1) || defined(ARDUINO_LABATHOME_15_2)
  TIM_FAN_LED_WHITE->setCaptureCompare(LED_WHITE_CH, power_0_100, PERCENT_COMPARE_FORMAT);
#endif
}

void SetPhysicalOutputs()
{
  // write rx_buffer to my outputs
#if defined(ARDUINO_LABATHOME_15_0) || defined(ARDUINO_LABATHOME_15_1) || defined(ARDUINO_LABATHOME_15_2)
  digitalWrite(PIN::RELAY, e2s_buffer.Relay);
#endif
  digitalWrite(PIN::BL_RESET, e2s_buffer.Blreset);
#if defined(ARDUINO_LABATHOME_15_1) || defined(ARDUINO_LABATHOME_15_2)
  digitalWrite(PIN::BL_SLEEP, e2s_buffer.Blsleep);
  // digitalWrite(PIN::LCD_RESET, e2s_buffer.LcdReset);
#endif
  // TODO USBC
  // HAL_DAC_SetValue(&hdac1, DAC1_CHANNEL_1, DAC_ALIGN_12B_R, ParseU16(esp2stm_buf, DAC1_POS));
  // HAL_DAC_SetValue(&hdac1, DAC1_CHANNEL_2, DAC_ALIGN_12B_R, ParseU16(esp2stm_buf, DAC2_POS));
  SetServoAngle(0, e2s_buffer.Servo[0]);
  SetServoAngle(1, e2s_buffer.Servo[1]);
  SetServoAngle(2, e2s_buffer.Servo[2]);
  SetServoAngle(3, e2s_buffer.Servo[3]);
  SetFanSpeed(e2s_buffer.Fan);
  SetLedPowerPower(e2s_buffer.LedPower);
  // SetHeaterPower: loop1ms automatically fetches correct value from buffer
  // TODO Brushless Mode
  if (e2s_buffer.ThreephaseMode == 0)
  {
    brushless_motor_velocity = e2s_buffer.ThreephaseP1;
  }
  // TODO Brushless Speeds
}

void setActorsToSafeSetting()
{
  memset((void *)&e2s_buffer, 0, sizeof(e2s_buffer));
  SetPhysicalOutputs();
}

void app_loop20ms(uint32_t now)
{
  led->Loop(now);

  // I2C_SLAVE::e2s_buffer[E2S::HEATER_POS] = encoder.GetTicks(); // COMMENT OUT FOR TESTING ONLY
  s2e_buffer.ButtonRed = digitalRead(PIN::BTN_RED);
  s2e_buffer.ButtonYellow = (!digitalRead(PIN::BTN_YELLOW));
  s2e_buffer.Movement = digitalRead(PIN::MOVEMENT);
  s2e_buffer.Blfault = (!digitalRead(PIN::BL_FAULT));
  s2e_buffer.Rotenc = encoder.GetTicks();
  s2e_buffer.Brightness = analogRead(PIN::BRIGHTNESS);
  s2e_buffer.UsbpdVoltage_mv = PowerSink.activeVoltage;
  //s2e_buffer.Adc0 = analogRead(PIN::ADC_0_U1T);
  //s2e_buffer.Adc1 = analogRead(PIN::ADC_1_U1R);
#if defined(ARDUINO_LABATHOME_15_2)
  s2e_buffer.PIN_PB12 = digitalRead(PIN::PIN_PB12);
  s2e_buffer.Adc2_24V = analogRead(PIN::ADC_2_24V);
// s2e_buffer.Adc3_Bl_i_sense=analogRead(PIN::BL_ISENSE); wrong, we do not read the input directly, but the OPAMPs output
#endif

  if (now >= timeToPutActorsInFailsafe)
  {
    if (!alreadySetToFailsafe)
    {
      log_warn("No Data from ESP32 - goto failsafe!");
      alreadySetToFailsafe = true;
      gotDataInfoAlreadyPrinted = false;
      setActorsToSafeSetting();
      SetBitIdx(s2e_buffer.Status, 2);
      led->AnimatePixel(millis(), &PROBLEM);
    }
  }
  else
  {
    if (!gotDataInfoAlreadyPrinted)
    {
      log_info("Got Data from ESP32");
      gotDataInfoAlreadyPrinted = true;
      led->AnimatePixel(millis(), &UNDER_CONTROL_FROM_MASTER);
    }
    alreadySetToFailsafe = false;
  }
}

char logBuffer1[96];
char logBuffer2[96];

void app_loop1000ms(uint32_t now)
{
  (void)now;

  // char* buf = errMan.GetLast8AsCharBuf_DoNotForgetToFree();
  byteBuf2hexCharBuf(logBuffer1, 96, (uint8_t *)&s2e_buffer, sizeof(s2e_buffer));
  byteBuf2hexCharBuf(logBuffer2, 96, (uint8_t *)&e2s_buffer, sizeof(e2s_buffer));
  log_info("enc=%d s2e=%s, e2s=%s", encoder.GetTicks(), logBuffer1, logBuffer2);
  // printf("printf\n");
  // Serial.printf("Serial.printf\n");
  // Serial4.printf("Serial4.printf\n");
}

void app_loop_superfast(uint32_t now)
{
  // Heater; Wert ist von 0-100; Zyklus dauert 1000ms
  static uint32_t startOfCycle = 0;
  time_t passedTime = now - startOfCycle;
  if (passedTime >= (10 * 100))
  {
    startOfCycle = now;
    if (e2s_buffer.Heater > 0)
    {
      digitalWrite(PIN::HEATER, HIGH);
    }
    else
    {
      digitalWrite(PIN::HEATER, LOW);
    }
  }
  else if (passedTime >= 10 * e2s_buffer.Heater)
  {
    digitalWrite(PIN::HEATER, LOW);
  }
}

void setup()
{

  led = new SINGLE_LED::M(PIN::LED_INFO, true, &WAITING_FOR_CONNECTION);
  led->Begin(millis(), &WAITING_FOR_CONNECTION, 10000);  
  Serial.begin(115200);
  
  log_info("Application started");
  
  
  log_info("Init gpio");
  pinMode(PIN::BTN_RED, INPUT);
  pinMode(PIN::BTN_YELLOW, INPUT);
  pinMode(PIN::MOVEMENT, INPUT);
  pinMode(PIN::BL_FAULT, INPUT);
  pinMode(PIN::HEATER, OUTPUT);
  pinMode(PIN::BRIGHTNESS, INPUT_ANALOG);

#if (defined(ARDUINO_LABATHOME_15_1) || defined(ARDUINO_LABATHOME_15_2))
  pinMode(PIN::RELAY, OUTPUT);
  pinMode(PIN::BL_SLEEP, OUTPUT);
  pinMode(PIN::BL_ISENSE, INPUT_ANALOG); // OPAMP2+
  pinMode(PIN::OPAMP3_M, INPUT_ANALOG);  // OPAMP3-
  pinMode(PIN::OPAMP3_P, INPUT_ANALOG);  // OPAMP3+
  pinMode(PIN::OPAMP3_Q, INPUT_ANALOG);  // OPAMP3+
  pinMode(PIN::SUPPLY_24V_SENSE, INPUT_ANALOG);

  hopamp2.Instance = OPAMP2;
  hopamp2.Init.PowerMode = OPAMP_POWERMODE_NORMALSPEED;
  hopamp2.Init.Mode = OPAMP_PGA_MODE;
  hopamp2.Init.NonInvertingInput = OPAMP_NONINVERTINGINPUT_IO1;
  hopamp2.Init.InternalOutput = ENABLE;
  hopamp2.Init.TimerControlledMuxmode = OPAMP_TIMERCONTROLLEDMUXMODE_DISABLE;
  hopamp2.Init.PgaConnect = OPAMP_PGA_CONNECT_INVERTINGINPUT_NO;
  hopamp2.Init.PgaGain = OPAMP_PGA_GAIN_4_OR_MINUS_3;
  hopamp2.Init.UserTrimming = OPAMP_TRIMMING_FACTORY;
  HAL_ERROR_CHECK(HAL_OPAMP_Init(&hopamp2));
  HAL_ERROR_CHECK(HAL_OPAMP_Start(&hopamp2));
#endif

#ifdef ARDUINO_LABATHOME_15_2
  pinMode(PIN::ADC_2_24V, INPUT_ANALOG);
  pinMode(PIN::LCD_RESET, INPUT);
  pinMode(PIN::BL_RESET, OUTPUT);
  pinMode(PIN::PIN_PB12, INPUT);
  //pinMode(PIN::ADC_0, INPUT_ANALOG);
  //pinMode(PIN::ADC_1, INPUT_ANALOG);
#endif

#ifdef ARDUINO_LABATHOME_15_3
  pinMode(PIN::ADC_2_24V, INPUT_ANALOG);
  pinMode(PIN::LCD_RESET, INPUT);
  pinMode(PIN::BL_RESET, OUTPUT);
  pinMode(PIN::PIN_PB12, INPUT);
#endif

  log_info("Init Rotary Encoder");
  encoder.Setup();

  log_info("Init Timer");
  // Problem: Die All-In-One-Funktion "setPWM" kann nur ganzzahlige Prozentangaben setzen, Dies ist zu Wenig für Servos
  // Lösung: Hier diese Funktion zum grundsätzlichen Initialisieren verwenden und oben die "setCaptureCompare"
#ifdef ARDUINO_LABATHOME_15_0
  TIM_LED_WHITE = new HardwareTimer(TIM4);
  TIM_SERVO_0_1 = new HardwareTimer(TIM15);
  TIM_SERVO_2 = new HardwareTimer(TIM16);
  TIM_FAN = new HardwareTimer(TIM17);

  TIM_LED_WHITE->setPWM(LED_WHITE_CH, PB_9_ALT1, 1000, 0);
  TIM_SERVO_0_1->setPWM(SERVO0_CH, PA_2_ALT1, 50, 0);
  TIM_SERVO_0_1->setPWM(SERVO1_CH, PA_3_ALT1, 50, 0);
  TIM_SERVO_2->setPWM(SERVO2_CH, PA_6_ALT1, 50, 0);
  TIM_FAN->setPWM(FAN_CH, PA_7_ALT3, 50, 0);
#elif defined(ARDUINO_LABATHOME_15_1)
  TIM_SERVO = new HardwareTimer(TIM1);
  TIM_SERVO->setPWM(SERVO0_CH, PC_0, 50, 0);
  TIM_SERVO->setPWM(SERVO1_CH, PC_1, 50, 0);
  TIM_SERVO->setPWM(SERVO2_CH, PC_2, 50, 0);
  TIM_SERVO->setPWM(SERVO3_CH, PC_3, 50, 0);

  TIM_FAN_LED_WHITE = new HardwareTimer(TIM15);
  TIM_FAN_LED_WHITE->setPWM(FAN_CH, PA_2_ALT1, 50, 0);
  TIM_FAN_LED_WHITE->setPWM(LED_WHITE_CH, PA_3_ALT1, 50, 0);

#elif defined(ARDUINO_LABATHOME_15_2)
  TIM_SERVO = new HardwareTimer(TIM1);
  TIM_SERVO->setPWM(SERVO0_CH, PC_0, 50, 0);
  TIM_SERVO->setPWM(SERVO1_CH, PC_1, 50, 0);
  TIM_SERVO->setPWM(SERVO2_CH, PC_2, 50, 0);
  TIM_SERVO->setPWM(SERVO3_CH, PC_3, 50, 0);

  TIM_FAN_LED_WHITE = new HardwareTimer(TIM15);
  TIM_FAN_LED_WHITE->setPWM(FAN_CH, PA_3_ALT1, 50, 0); // PA2 and PA3 changed from LabAtHome15.1 to 15.2
  TIM_FAN_LED_WHITE->setPWM(LED_WHITE_CH, PA_2_ALT1, 50, 0);

#elif defined(ARDUINO_LABATHOME_15_3)
  log_info("Init ServoBus");
  ServoBusSerial.begin(1000000, SERIAL_8N1);
  //servoBus.pSerial = &ServoBusSerial;
  bool dummy=true;
  while(true){
    log_info("servoBus.Ping(5) returns %d",servoBus.Ping(5));
    servoBus.WritePosEx(5, 4095, 3400, 50);//servo(ID1) speed=3400，acc=50，move to position=4095.
    delay(2000);
    servoBus.WritePosEx(5, 2000, 1500, 50);//servo(ID1) speed=3400，acc=50，move to position=2000.
     delay(2000);
    led->Force(dummy);
    dummy = !dummy;
  }
  log_info("Init StepperSerial");
  StepperSerial.begin(115200);
  pinMode(PIN::STEPPER_EN, OUTPUT);
  pinMode(PIN::FAN_SERVO4_STEPPER3_DIR, OUTPUT);
  pinMode(PIN::LED_WHITE_P_SERVO5_STEPPER3_STEP, OUTPUT);
  digitalWrite(PIN::STEPPER_EN, LOW); // Enable driver in hardware
  /*
    stepperdriver.begin();
    stepperdriver.toff(5);                 // Enables driver in software
    stepperdriver.rms_current(600);        // Set motor RMS current
    stepperdriver.microsteps(16);          // Set microsteps to 1/16th
    //StealthChop=Leise
    stepperdriver.pwm_autoscale(true);     // Needed for stealthChop
    */
  stepperdriver.setup(StepperSerial, 115200, TMC2209::SERIAL_ADDRESS_0);
  delay(2000);

  stepperdriver.setRunCurrent(100);
  stepperdriver.enableCoolStep();
  stepperdriver.enable();
  stepperdriver.moveAtVelocity(20000);

  

#endif


  log_info("Init USB PD");
  PowerSink.start(USB_PD::handleUsbPdEvent);

  log_info("Init I2C");
  memset(&s2e_buffer, 0, sizeof(s2e_buffer));
  setActorsToSafeSetting();

  Wire.setSDA(PIN::SDA);
  Wire.setSCL(PIN::SCL);
  Wire.begin(I2C_SETUP::STM32_I2C_ADDRESS);

  SimpleFOCDebug::enable(&Serial);

  // driver config
  // power supply voltage [V]
  bldcdriver.voltage_power_supply = 12;
  // limit the maximal dc voltage the driver can set
  // as a protection measure for the low-resistance motors
  // this value is fixed on startup
  bldcdriver.voltage_limit = 6;
  if (!bldcdriver.init())
  {
    log_error("Driver init failed!");
    return;
  }
  // link the motor and the driver
  bldcmotor.linkDriver(&bldcdriver);

  // limiting motor movements
  // limit the voltage to be set to the motor
  // start very low for high resistance motors
  // current = voltage / resistance, so try to be well under 1Amp
  bldcmotor.voltage_limit = 3; // [V]

  // open loop control config
  bldcmotor.controller = MotionControlType::velocity_openloop;

  // init motor hardware
  if (!bldcmotor.init())
  {
    log_error("Motor init failed!");
    return;
  }
  log_info("Motor ready!");

  log_info("Init completed - eternal loop starts");
}

void loop_servotest()
{
  int pos;
  for (pos = 0; pos <= 180; pos += 1)
  { // goes from 0 degrees to 180 degrees
    // in steps of 1 degree
    SetServoAngle(0, pos); // tell servo to go to position in variable 'pos'
    SetServoAngle(1, pos);
    SetServoAngle(2, pos);
    delay(15); // waits 15ms for the servo to reach the position
  }
  for (pos = 180; pos >= 0; pos -= 1)
  {                        // goes from 180 degrees to 0 degrees
    SetServoAngle(0, pos); // tell servo to go to position in variable 'pos'
    SetServoAngle(1, pos);
    SetServoAngle(2, pos);
    delay(15); // waits 15ms for the servo to reach the position
  }
}

void loop_default()
{
  PowerSink.poll();
  bldcmotor.move(brushless_motor_velocity);
  static uint32_t last20ms = 0;
  static uint32_t last1000ms = 0;
  uint32_t now = millis();
  app_loop_superfast(now);
  uint32_t timePassed20 = now - last20ms;
  if (timePassed20 >= 20)
  {
    last20ms = now;
    app_loop20ms(now);
  }
  uint32_t timePassed1000 = now - last1000ms;
  if (timePassed1000 >= 1000)
  {
    last1000ms = now;
    app_loop1000ms(now);
  }
}
#if defined(ARDUINO_LABATHOME_15_3)
bool shaft = false;

void loop_steppertest()
{
  
  if (stepperdriver.isSetupAndCommunicating())
  {
    Serial.println("Stepper driver is setup and communicating!");
    Serial.println("Try turning driver power off to see what happens.");
  }
  else if (stepperdriver.isCommunicatingButNotSetup())
  {
    Serial.println("Stepper driver is communicating but not setup!");
    Serial.println("Running setup again...");
    stepperdriver.setup(stepper_serial_stream);
  }
  else
  {
    Serial.println("Stepper driver is not communicating!");
    Serial.println("Try turning driver power on to see what happens.");
  }
  Serial.println();
  delay(3000);
  /*
  // Run 5000 steps and switch direction in software
  for (uint16_t i = 5000; i>0; i--) {
    digitalWrite(PIN::LED_WHITE_P_SERVO5_STEPPER3_STEP, HIGH);
    delayMicroseconds(160);
    digitalWrite(PIN::LED_WHITE_P_SERVO5_STEPPER3_STEP, LOW);
    delayMicroseconds(160);
  }
  shaft = !shaft;
  stepperdriver.shaft(shaft);
  */
}

void loop_busservotest(){
  servoBus.WritePosEx(5, 4095, 3400, 50);//servo(ID1) speed=3400，acc=50，move to position=4095.
  delay(2000);
  
  servoBus.WritePosEx(5, 2000, 1500, 50);//servo(ID1) speed=3400，acc=50，move to position=2000.
  delay(2000);
}
#endif

void loop()
{
  loop_default();
}

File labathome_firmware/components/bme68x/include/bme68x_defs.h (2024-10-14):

/**
* Copyright (c) 2023 Bosch Sensortec GmbH. All rights reserved.
*
* BSD-3-Clause
*
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
* 1. Redistributions of source code must retain the above copyright
*    notice, this list of conditions and the following disclaimer.
*
* 2. Redistributions in binary form must reproduce the above copyright
*    notice, this list of conditions and the following disclaimer in the
*    documentation and/or other materials provided with the distribution.
*
* 3. Neither the name of the copyright holder nor the names of its
*    contributors may be used to endorse or promote products derived from
*    this software without specific prior written permission.
*
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
* @file       bme68x_defs.h
* @date       2023-02-07
* @version    v4.4.8
*
*/

/*! @cond DOXYGEN_SUPRESS */

#ifndef BME68X_DEFS_H_
#define BME68X_DEFS_H_

/********************************************************* */
/*!             Header includes                           */
/********************************************************* */
#ifdef __KERNEL__
#include <linux/types.h>
#include <linux/kernel.h>
#else
#include <stdint.h>
#include <stddef.h>
#endif

/********************************************************* */
/*!               Common Macros                           */
/********************************************************* */
#ifdef __KERNEL__
#if !defined(UINT8_C) && !defined(INT8_C)
#define INT8_C(x)    S8_C(x)
#define UINT8_C(x)   U8_C(x)
#endif

#if !defined(UINT16_C) && !defined(INT16_C)
#define INT16_C(x)   S16_C(x)
#define UINT16_C(x)  U16_C(x)
#endif

#if !defined(INT32_C) && !defined(UINT32_C)
#define INT32_C(x)   S32_C(x)
#define UINT32_C(x)  U32_C(x)
#endif

#if !defined(INT64_C) && !defined(UINT64_C)
#define INT64_C(x)   S64_C(x)
#define UINT64_C(x)  U64_C(x)
#endif
#endif

/*! C standard macros */
#ifndef NULL
#ifdef __cplusplus
#define NULL         0
#else
#define NULL         ((void *) 0)
#endif
#endif

#ifndef BME68X_DO_NOT_USE_FPU

/* Comment or un-comment the macro to provide floating point data output */
#define BME68X_USE_FPU
#endif

/* Period between two polls (value can be given by user) */
#ifndef BME68X_PERIOD_POLL
#define BME68X_PERIOD_POLL                        UINT32_C(10000)
#endif

/* BME68X unique chip identifier */
#define BME68X_CHIP_ID                            UINT8_C(0x61)

/* Period for a soft reset */
#define BME68X_PERIOD_RESET                       UINT32_C(10000)

/* BME68X lower I2C address */
#define BME68X_I2C_ADDR_LOW                       UINT8_C(0x76)

/* BME68X higher I2C address */
#define BME68X_I2C_ADDR_HIGH                      UINT8_C(0x77)

/* Soft reset command */
#define BME68X_SOFT_RESET_CMD                     UINT8_C(0xb6)

/* Return code definitions */
/* Success */
#define BME68X_OK                                 INT8_C(0)

/* Errors */
/* Null pointer passed */
#define BME68X_E_NULL_PTR                         INT8_C(-1)

/* Communication failure */
#define BME68X_E_COM_FAIL                         INT8_C(-2)

/* Sensor not found */
#define BME68X_E_DEV_NOT_FOUND                    INT8_C(-3)

/* Incorrect length parameter */
#define BME68X_E_INVALID_LENGTH                   INT8_C(-4)

/* Self test fail error */
#define BME68X_E_SELF_TEST                        INT8_C(-5)

/* Warnings */
/* Define a valid operation mode */
#define BME68X_W_DEFINE_OP_MODE                   INT8_C(1)

/* No new data was found */
#define BME68X_W_NO_NEW_DATA                      INT8_C(2)

/* Define the shared heating duration */
#define BME68X_W_DEFINE_SHD_HEATR_DUR             INT8_C(3)

/* Information - only available via bme68x_dev.info_msg */
#define BME68X_I_PARAM_CORR                       UINT8_C(1)

/* Register map addresses in I2C */
/* Register for 3rd group of coefficients */
#define BME68X_REG_COEFF3                         UINT8_C(0x00)

/* 0th Field address*/
#define BME68X_REG_FIELD0                         UINT8_C(0x1d)

/* 0th Current DAC address*/
#define BME68X_REG_IDAC_HEAT0                     UINT8_C(0x50)

/* 0th Res heat address */
#define BME68X_REG_RES_HEAT0                      UINT8_C(0x5a)

/* 0th Gas wait address */
#define BME68X_REG_GAS_WAIT0                      UINT8_C(0x64)

/* Shared heating duration address */
#define BME68X_REG_SHD_HEATR_DUR                  UINT8_C(0x6E)

/* CTRL_GAS_0 address */
#define BME68X_REG_CTRL_GAS_0                     UINT8_C(0x70)

/* CTRL_GAS_1 address */
#define BME68X_REG_CTRL_GAS_1                     UINT8_C(0x71)

/* CTRL_HUM address */
#define BME68X_REG_CTRL_HUM                       UINT8_C(0x72)

/* CTRL_MEAS address */
#define BME68X_REG_CTRL_MEAS                      UINT8_C(0x74)

/* CONFIG address */
#define BME68X_REG_CONFIG                         UINT8_C(0x75)

/* MEM_PAGE address */
#define BME68X_REG_MEM_PAGE                       UINT8_C(0xf3)

/* Unique ID address */
#define BME68X_REG_UNIQUE_ID                      UINT8_C(0x83)
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

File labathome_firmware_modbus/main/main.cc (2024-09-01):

constexpr int FIRMWARE_VERSION{5};
// Hints for the command line test software "modpoll", that I used during development
//In this tool, the register addresses ("r") is 1-based
// COMxy has to be replaced with your specific com port.

//Query Inputs:      modpoll -r 1 -c 9 -t 1 -b 9600 COM17
//Set Coil Outputs:  modpoll -r 1 -c 1 -t 0 -b 9600 COM17 0
//Set LED Color      modpoll -r 10 -c 1 -t 4 -b 9600 COM17 65535
//Set Servo          modpoll -r 2 -c 1 -t 4 -b 9600 COM7 50

/*
These are the addresses and the formats at LabAtHome
Adresses are 0-Based
Coils:
 0: Relay K3

Discrete Input:
 0: Green Button
 1: Red Button
 2: Yellow Button / Encoder Button
 3: Movement Sensor

Holding Registers:
 0: Not connected
 1: Servo 0, Position in Degrees 0...180
 2: Servo 1, Position in Degrees 0...180
 3: Servo 2, Position in Degrees 0...180
 4: Servo 3, Position in Degrees 0...180
 5: Fan 0, Power in Percent 0...100
 6: Fan 1, Power in Percent 0...100
 7: Heater, Power in Percent 0...100
 8: White Power LED, Power in Percent 0...100
 9: RGB LED 0, Color in RGB565
 10: LED 1
 11: LED 2
 12: LED 3
 13: Relay State (Alternative to Coil 0), 0 means off, all other values on
 14: Play Sound, 0 means silence; try other values up to 9

Input Registers:
 0: CO2 [PPM]
 1: Air Pressure [hPa]
 2: Ambient Brightness [?]
 3: Analog Input [mV] //CHANNEL_ANALOGIN_OR_ROTB I34
 4: Button Green [0 or 1]
 5: Button Red [0 or 1]
 6: Button Yellow/Encoder [0 or 1]
 7: Fan 1 RpM
 8: Heater Temperature [°C * 100] (Temperatur des "Dreibeiners")
 9: Encoder Detents
10: Movement Sensor [0 or 1]
11: Distance Sensor [millimeters]
12: Analog Voltage on Pin 35 //CHANNEL_MOVEMENT_OR_FAN1SENSE I35
13: placeholder
14: placeholder
15: Relative Humidity AHT21 [%]
16: Temperature AHT21 [°C * 100]
17: Relative Humidity BME280 [%]
18: Temperature BME280 [°C * 100]
100: Firmware Version
                
*/

#include <cstdio>
#include <cstdint>
#include <cstring>
#include "esp_log.h"
#include "freertos/FreeRTOS.h"
#include "freertos/task.h"
#include "freertos/semphr.h"
#include "sdkconfig.h"
#include "esp_timer.h"
#include "modbusslave.hh"
#include <vector>
#include <driver/uart.h>
#include <common.hh>
#include <array>
#include <nvs_flash.h>
#include <spiffs.hh>
#include <wifi_sta.hh>


static const char *TAG = "main";

#include "HAL.hh"
#if (CONFIG_IDF_TARGET_ESP32)
    #include "HAL_labathomeV10.hh"
    static HAL * hal = new HAL_Impl(MODE_MOVEMENT_OR_FAN1SENSE::MOVEMENT_SENSOR);
#elif(CONFIG_IDF_TARGET_ESP32S3)
#include "HAL_labathomeV15.hh"
static HAL * hal = new HAL_Impl();
#endif

constexpr TickType_t xFrequency {pdMS_TO_TICKS(50)};

modbus::M<100000> *modbusSlave;

constexpr size_t COILS_CNT{16};
constexpr size_t DISCRETE_INPUTS_CNT{16};
constexpr size_t INPUT_REGISTERS_CNT{101};
constexpr size_t HOLDING_REGISTERS_CNT{16};

static std::vector<bool> coilData(COILS_CNT);
static std::vector<bool> discreteInputsData(DISCRETE_INPUTS_CNT);
static std::vector<uint16_t> inputRegisterData(INPUT_REGISTERS_CNT);
static std::vector<uint16_t> holdingRegisterData(HOLDING_REGISTERS_CNT);
#define NVS_PARTITION_NAME NVS_DEFAULT_PART_NAME


void modbusAfterWriteCallback(uint8_t fc, uint16_t start, size_t len){
    
    if(fc==15 || fc==5){
        bool b=coilData.at(start);
        ESP_LOGI(TAG, "Modbus Coil Registers changed! fc:%d, start:%d len:%d, firstChangedBit=%d", fc, start, len, b);
        for(int i=start;i<start+len;i++){
            switch (i)
            {
            case 0:
                hal->SetRelayState(coilData.at(0));
                break;
            default:
                break;
            }
        }
    }
    else if(fc==16 || fc==6){
        ESP_LOGI(TAG, "Modbus Output Registers changed! fc:%d, start:%d len:%d, firstChangesValues=%d", fc, start, len, holdingRegisterData.at(start));
        
        for(int reg=start;reg<start+len;reg++){
            switch (reg)
            {
            case 0:
                break;
            case 1:
                hal->SetServoPosition(0, holdingRegisterData.at(reg));
                break;
            case 2:
                hal->SetServoPosition(1, holdingRegisterData.at(reg));
                break;
            case 3:
                hal->SetServoPosition(2, holdingRegisterData.at(reg));
                break;
            case 4:
                hal->SetServoPosition(3, holdingRegisterData.at(reg));
                break;
            case 5:
                hal->SetFanDuty(0, holdingRegisterData.at(reg));
                break;
            case 6:
                hal->SetFanDuty(1, holdingRegisterData.at(reg));
                break;
            case 7:
                hal->SetHeaterDuty(holdingRegisterData.at(reg));
                break;
            case 8://PowerWhite
                hal->SetLedPowerWhiteDuty(holdingRegisterData.at(reg));
                break;
            case 9://RGB LED 0, this number has to be inserted in call in "case 12"
            case 10:
            case 11:
            case 12: //RGB LED 3
                hal->ColorizeLed(reg-9, CRGB::FromRGB565(holdingRegisterData.at(reg)));
                break;
            case 13:
                hal->SetRelayState(holdingRegisterData.at(reg));
                break;
            case 14:
                hal->SetSound(holdingRegisterData.at(reg));
                break;
            default:
                break;
            }
        }
    }
}
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

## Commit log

2020-04-18 Improved Layout
    [labAThome.kicad_pcb, labAThome.sch]
2020-05-07 PCB REV2
    [labAThome.kicad_pcb, labAThome.sch]
2020-06-18 PCB V2 RC1
    [labAThome.kicad_pcb, labAThome.sch]
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2020-06-22 PCB V2 as ordered
    [labAThome-B_Cu.gbr, labAThome-B_Mask.gbr, labAThome-B_SilkS.gbr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]
2020-06-26 DoubleRow VPS connector; Various 3D models
    [labAThome.kicad_pcb, labAThome.sch]
2020-06-28 Slight optimizations in PCB
    [labAThome.kicad_pcb]
2020-07-25 SchematicsV3 as ordered at JLCPCB
    [PinHints.xlsx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]
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2020-08-11 PCB V4 as ordered at JLCPCB
    [labAThome BOM Cost.xlsx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]
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2020-08-25 PCB last version without SMD
    [GSM.sch, labAThome.kicad_pcb, labAThome.sch]
2020-08-29 PCB labathomev5 as ordered at jlcpcb
    [GSM.sch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]
2020-09-20 Various big changes (sorry for beeing rude here...)
    [labAThome.kicad_pcb, labAThome.sch, labAThomeV5_bom.csv]
2020-09-26 labathome - first break through - simple and/or/rs working :-)
    [labAThome.kicad_pcb, labAThome.sch]
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2020-10-16 V0.1 ready for testing :-)
    [labAThome.kicad_pcb]
2020-10-23 labathome V5.1 as ordered at JLCPCB
    [labAThome-B_Cu.gbr, labAThome-B_Mask.gbr, labAThome-B_SilkS.gbr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]
2020-11-02 Simulation Mode in WebUI
    [Test.xlsx, labAThome.kicad_pcb]
2020-11-14 heaterEmergencyShutdown fix
2021-06-01 lab@home5.3 as ordered at jlcpcb
    [I2S_AMP.sch, analog_amp.sch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]
2021-06-04 I2S-Amp --> Analog (damn cheap) Amp
    [analog_amp.sch, labAThome.sch]
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2021-08-09 labathome V6 as ordered at JLCPCB
    [labAThome-B_Cu.gbl, labAThome-B_Mask.gbs, labAThome-B_Paste.gbp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]
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2021-09-14 Added option description for PCB
    [analog_amp.sch, labAThome BOM V6.xlsx, labAThome.sch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]
2021-09-14 Added PCB V10 as ordered at JLCPCB
    [PinHints.xlsx, analog_amp.sch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]
2021-11-25 pcb V10 as ordered at JLCPCB
    [BOM.xlsx, analog_amp.sch, labAThome.kicad_pcb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]
2022-01-01 labathome v11 as ordered @ JLCPCB
    [FastFourierTransform.xlsx, analog_amp.sch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]
2022-01-07 Moved all components to esp-idf components repository
    [analog_amp.sch, pcbV10.csv, pcbV10.kicad_pcb]
2022-03-02 All SMD components orderable @ JLCPCB
    [BOM-pcbV10.csv, BOM-pcbV10_front.csv, analog_amp.kicad_sch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]
2022-03-18 PCBs as ordered at JLCPCB with assembly
    [BOM-pcbV10.csv, BOM-pcbV10_front.csv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]
2022-03-27 Updated capacitor JLCPCB, Removed unnecessary Files
    [BOM.xlsx, analog_amp.sch, pcbV10 - Kopie.kicad_pcb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]
2022-04-04 Minor fixes in PCB
    [BOM-pcbV10.csv, BOM-pcbV10_front.csv, Issue Tracker.xlsx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]
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2022-05-12 Deleted old pcb version - never go back to these times ;-)
    [GSM.sch, I2S_AMP.sch, PinHints.xlsx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]
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2022-06-22 Bugfix: digital amplifier not in standby
    [analog_amp.kicad_sch, pcbV10.kicad_pcb, pcbV10.kicad_sch]
2022-07-01 Boris Integration; some code rework
    [devicemanager.cc, main.cc]
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2022-07-25 RGB-LED bugfix
2022-09-03 Minor fixes
    [pcbV10.kicad_pcb]
2022-09-08 Updated PCB: nRF24l01, SIM7080, LoRa module
    [analog_amp.kicad_sch, pcbV10.kicad_pcb, pcbV10.kicad_sch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]
2022-09-28 PCB as ordered at JLCPCB
    [pcbV10.kicad_pcb, pcbV10.kicad_sch]
2022-12-08 LTSpice Simulation & minor optical fixes
    [Bausatz Teilebedarf.xlsx, analog_amp.kicad_sch, pcbV10.kicad_pcb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]
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2023-10-20 Fix Movement Sensor
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2024-07-05 labathome_pcb15 ready for first review
    [actors.kicad_sch, labathome_pcb15.kicad_pcb, slave_cpu.kicad_sch]
2024-07-06 labathome_pcb5 ready for review, 2nd
    [BOM-labathome_pcb15.csv, BOM-pcbV10.csv, actors.kicad_sch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]
2024-07-08 Various PCB and Code updates after review from Jana Marie Hemsing. Big Thankyou
    [BOM-labathome_pcb15.csv, actors.kicad_sch, audioamplifier.kicad_sch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]
2024-07-08 Further improventents in PCB layout
    [BOM-labathome_pcb15.csv, actors.kicad_sch, audioamplifier.kicad_sch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]
2024-07-08 Final PCB as ordered @ JLCPCB
    [BOM-labathome_pcb15.csv, audioamplifier.kicad_sch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]
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2024-08-16 Added stm32 arduino firmware
    [labathome_pcb15.kicad_pcb]
2024-08-20 Updates in PCB, arduino test firmware
    [actors.kicad_sch, audioamplifier.kicad_sch, communication.kicad_sch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]
2024-08-20 Re-enumerate Servos and Fans
    [actors.kicad_sch, labathome_pcb15.kicad_pcb, slave_cpu.kicad_sch]
2024-08-22 Cosmetics (improved ground planes, more vias)
    [labathome_pcb15.kicad_pcb]
2024-08-22 Various bugfixes for the stm32 arduino firmware
    [main.cpp]
2024-08-23 Various Bugfixes after testing modbus and open loop heater experiment
    [devicemanager.cc, main.cc, main.cpp]
2024-08-29 Reverse mount LEDs, switch
    [BOM-labathome_pcb15.csv, actors.kicad_sch, audioamplifier.kicad_sch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]
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2024-09-02 PCB update IP5306 I2C
    [labathome_pcb15.kicad_pcb, labathome_pcb15.kicad_sch, psu.kicad_sch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]
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2024-09-04 labathome 15.1 as ordered @ JLCPCB
    [BOM-labathome_pcb15.csv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]
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2024-09-29 Various changes / bugfixes / refactorings
    [labathome_pcb15.kicad_sch, slave_cpu.kicad_sch]
2024-10-03 ec11 smd, LCD Reset from ESP32 with jumper, six servos
    [actors.kicad_sch, labathome_pcb15.kicad_sch, slave_cpu.kicad_sch]
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2024-10-11 Updated PCB, sensprs as JSON
    [actors.kicad_sch]
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2024-10-17 Labathome 15.2 as ordered at JLCPCB
    [BOM-labathome_pcb15.csv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]
2024-11-04 PCB 15.2 as ordered @ JLCPCB; database backed build process
    [labathome_pcb15-CuBottom.gbr, labathome_pcb15-CuIn1.gbr, labathome_pcb15-CuIn2.gbr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]
2024-11-06 Fixes for 15.2 and 15.ß
    [labathome_pcb15.kicad_sch, psu.kicad_sch]
2024-11-07 LCD Fix, builder fix
    [main.cpp]
2024-11-15 Added Stepper Motors (initial)
    [actors.kicad_sch, labathome_pcb15.kicad_sch, stepper2209.kicad_sch]
2024-11-15 Merged and fixed (WIP)
    [stepper2209.kicad_sch]
2024-11-19 Added stepper, no DRC errors, not yet optimized
    [actors.kicad_sch, communication.kicad_sch, psu.kicad_sch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]
2024-11-22 PCB update; DRC check passed; optimized routing
    [labathome_pcb15.kicad_sch]
2024-11-22 Layout improvement; use common enable signal for steppers
    [labathome_pcb15.kicad_sch, slave_cpu.kicad_sch, stepper2209.kicad_sch]
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2024-11-27 Flowchart is displayed correctly
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2024-11-30 Continued with severe refactoring. Now builds, but completely untested
    [labathome_pcb.kicad_sch, psu.kicad_sch]
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2025-01-19 Integration of old "webmanager" code (untested)
    [actors.kicad_sch, audioamplifier.kicad_sch, psu.kicad_sch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]
2025-01-23 Bugfixes, moved testserver websocket handlers to external package
    [main.cc]
2025-01-23 Minor improments on pcb
    [audioamplifier.kicad_sch, labathome_pcb.kicad_sch, psu.kicad_sch]
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2025-03-03 Various Fixes and improvements in building process
    [main.cc]
2025-03-06 Labathome PCB -> KICAD 9
    [actors.kicad_sch, audioamplifier.kicad_sch, communication.kicad_sch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]
2025-03-11 Fixed heaterexperiment crash; renamed all flatbuffers to include namespace
    [devicemanager.cc]
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2026-09-21 Switch to C# builder, support Rev. 5.x (classic ESP32), migrate to BestBinaryBuffers
    - builder/: replace the Gulp/TypeScript orchestrator by a C# builder based on
    firmware_builder_common (steps: Pipeline, PipelineBuildOnly, SetBoardVersion,
    GenerateSounds via Google TTS, ...). Generated files now live in generated/.
    - Board version is zero-padded to six digits (50100 -> "05") to select main/hal/<major>
    and the IDF target (esp32 for Rev. <= 5, esp32s3 otherwise); per-target build dir,
    sdkconfig, defaults and partition table (factory + storage, no OTA on the 4 MB ESP32).
    - HAL 05 rewritten for iHAL and the ESP-IDF 6.0 drivers (MCPWM, I2C master, ADC oneshot);
    TinyUSB/Modbus/temperatu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
    [partitions_esp32.csv]
2026-09-23 Vervollstaendige designated initializers, fixe Heater-Modus-Anzeige
    - main.cc/hal_impl.hh: fehlende Felder in tinyusb_config_t,
    esp_vfs_littlefs_conf_t und i2c_master_bus_config_t.flags ergaenzt
    (silenced -Wmissing-field-initializers, keine Verhaltensaenderung)
    - heater_experiment_controller.ts:
    - onModeChange() liess beim ersten Aufruf (Default-Modus
    FUNCTION_BLOCK == this.mode) alle Steuerelemente sichtbar, weil
    der fruehe Guard "newMode==this.mode" den Sichtbarkeits-Switch
    uebersprang; Guard entfernt (Funktion ist idempotent)
    - T_N/T_V: max/step entfernt, nur min="0" bleibt
    [main.cc]
2026-09-23 testserver: node-forge/ws/jsdiff auf gepatchte Versionen aktualisiert
    Behebt alle 9 von GitHub Dependabot gemeldeten Alerts (7x high, 2x moderate)
    in testserver/package-lock.json:
    - node-forge 1.3.1 -> 1.4.0 (GHSA-2328-f5f3-gj25, -q67f-28xg-22rw,
    -ppp5-5v6c-4jwp, -5m6q-g25r-mvwx, -554w-wpv2-vw27, -65ch-62r8-g69g,
    -5gfm-wpxj-wjgq)
    - ws 8.18.0 -> 8.21.3 (GHSA-96hv-2xvq-fx4p, -58qx-3vcg-4xpx)
    - zusaetzlich per "npm audit fix" eine low-severity ReDoS-Luecke in
    diff/jsdiff (nicht in der Dependabot-Liste, beim Gegenchecken aufgefallen)
    package.json unveraendert (Ranges ^1.3.1/^8.14.2 erlaubten die neueren
    Versionen schon), nur package-lock.json aktualisiert. testserver ist ein
    lokales Dev-T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
